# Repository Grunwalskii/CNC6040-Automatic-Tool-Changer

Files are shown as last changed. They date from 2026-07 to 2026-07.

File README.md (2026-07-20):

# CNC6040 Tool Changer

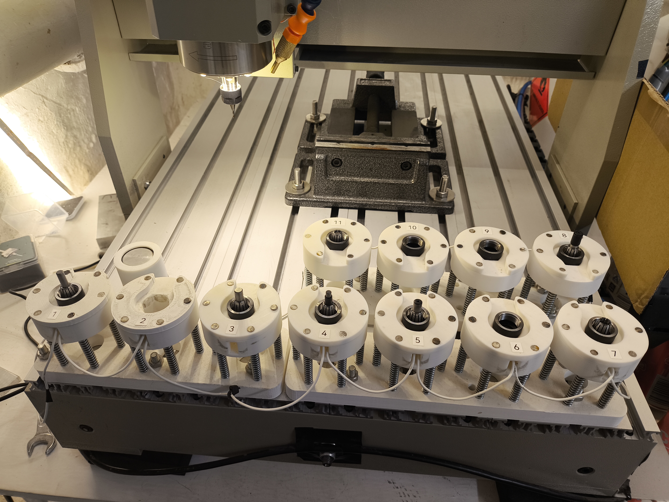
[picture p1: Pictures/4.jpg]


# CNC6040 Tool Changer Configuration & Setup Guide

## Software & Hardware Integration

### 1. Fusion 360 Tool Change Bypass (Personal/Non-Commercial Tier)
The free personal tier of Autodesk Fusion 360 restricts multi-tool operations by stripping out automatic tool change commands (`M6`) and forcing the generation of separate, individual G-code files for each tool. To bypass this limitation and preserve continuous tool paths in a single output file, you must use a batch post-processing add-in.

* **Bypass Tool:** Download and install the [Fusion360-Batch-Post Add-In by TimPaterson](https://github.com/TimPaterson/Fusion360-Batch-Post).
* **Configuration:** 
  1. Open the **Post Process All** menu inside your Fusion 360 Manufacture workspace.
  2. Locate the patch settings area.
  3. Ensure that the **"Use individual operations"** option is enabled/configured as demonstrated in the system images, which re-links operations across multiple tools into a unified G-code sequence.
  4. Ensure your post-processor settings are matched exactly to your specific machine variant's configuration image.

---

### 2. Mach3 Modern Control Interface
To replace the outdated stock Mach3 user interface with a streamlined, modern layout optimized for rapid setup and clear digital readouts (DRO), this build uses a high-performance custom screen set.

* **Control Interface:** [PA Mach 3 Screen Set by Physics Anonymous](https://www.physanon.com/pa-mach-3-screen-set/).
* **Installation:** Extract the downloaded file structure. Place the custom `.set` file directly inside your root `C:\Mach3\` directory, and copy the accompanying UI asset folders into the `Mach3\Bitmaps\` folder. Load the new interface from the Mach3 upper menu bar under **View -> Load Screens**.

---

### 3. CNC6040 USB Control Board Modifications
To safely automate tool change heights and verify secure tool engagement, the standard CNC6040 USB interface board has been modified to accept two dedicated digital inputs:

* **Electric Touch Probe:** Assigned to a specific digital input pin for automatic tool height probing. The spindle/tool must be properly grounded to the CNC chassis. The touchplate is wired directly to the signal line from the controller board, utilizing an internal or external pull-up resistor (configured as Default High) that triggers the circuit when the tool makes physical contact.
* **Tool Presence Sensors:** Implemented inside each tool slot/pocket of the rack using tactile microswitches wired in series to monitor tool insertion status. Because they are chained together, the signal pulls **High** if any single switch is open (indicating a missing or improperly seated tool), and drops **Low** only when all tools are securely in place, instantly halting operations if a tool fails to mount or unmount correctly.
* **Limit Switch Configuration:** To free up and maximize the available input pins on the USB control board for the probe and tool presence sensors, all three physical axis limit switches (X, Y, and Z) have been wired in series to share a single, combined digital input pin.

### 4. Materials & Bill of Materials (BOM)

#### 3D Printed Parts
* **Print Settings:** Print all provided STL files using any standard structural filament (e.g.,PLA, PETG, ABS, or ASA). 
* **Perimeters:** A minimum of **3 wall perimeters**
* **Infill:** A minimum of 20%
  
#### Hardware & Components
To complete the assembly, you will need to source the following off-the-shelf items:

1. **Linear Rods:** 5mm diameter steel rods (Available on [AliExpress](https://de.aliexpress.com/item/4001203233924.html)).
2. **Spring Steel Springs:** 
   * **Wire Diameter:** 0.5 mm
   * **Outer Diameter:** 6.5 mm
   * **Length:** 35 mm
3. Microswitches (Type: HANDLE Available on [AliExpress](https://de.aliexpress.com/item/1005009576690625.html))
4. M6 Screws ~25mm and Nuts
5. Some kind of touchplate (Available on [AliExpress](https://de.aliexpress.com/item/1005008850006833.html)
   
---

## Support

If you enjoy this project and want to support its development, you can buy me a coffee:



---

## ⚠️ Disclaimer & Danger Warning

### 🛑 DANGER: RISK OF MACHINE CRASH & HARDWARE DAMAGE
**Misconfigured tool height sensors, incorrect G-code, or improper macro settings will cause a severe machine crash.** 
Before allowing the spindle to automatically drive a tool down into the touchplate or tool setter, you **must** manually test the circuit logic.

### Disclaimer
This documentation and the provided configurations are shared for educational and personal project use only. Modifying CNC machinery with custom automatic tool changers, custom macro scripts, and un-isolated input circuits carries inherent risks of hardware destruction, electrical damage, and personal injury. The authors assume no liability for damaged components, broken tooling, or ruined workpieces resulting from the use of these guides or files. Proceed at your own risk.

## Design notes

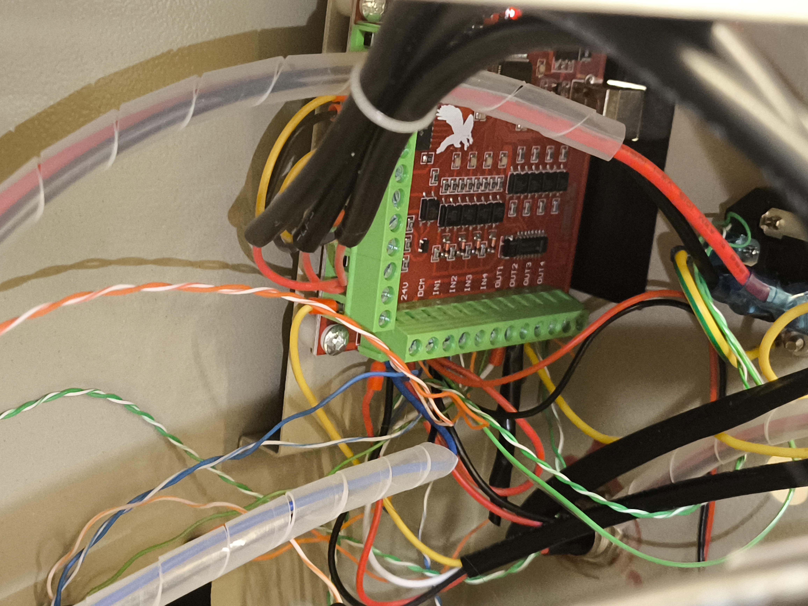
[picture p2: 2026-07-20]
Pictures/CNC6040ControlBoard.jpg

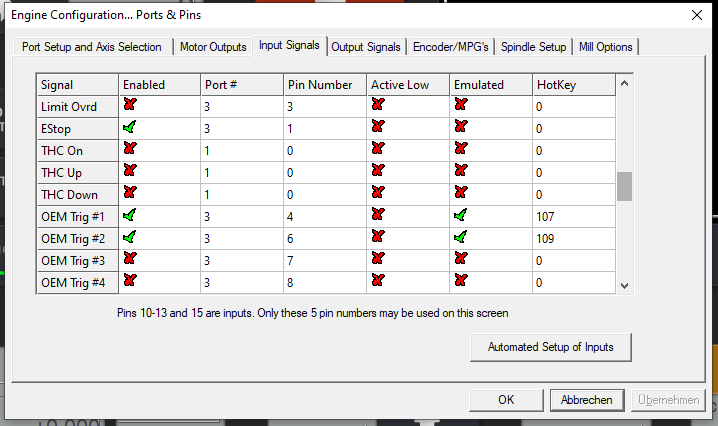
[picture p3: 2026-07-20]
Mach3/Screenshots/{6C5813CC-ED11-40CD-9C9B-76047EAF6F08}.png

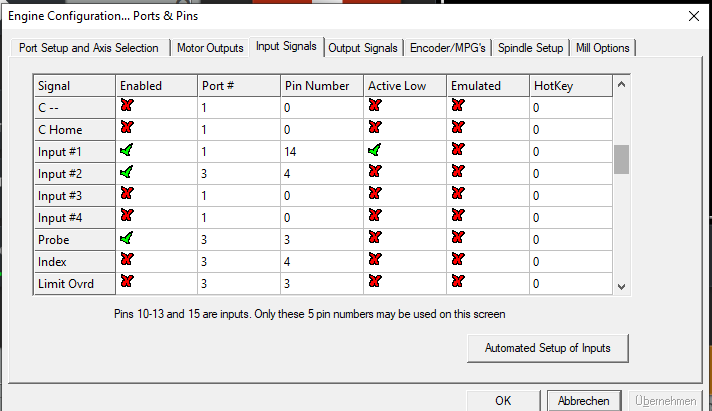
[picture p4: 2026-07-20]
Mach3/Screenshots/{B6C7E7E9-AD3A-4B73-86B3-040BA170EC96}.png

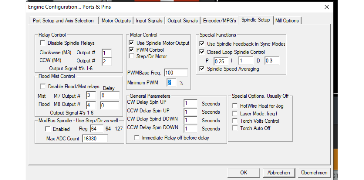
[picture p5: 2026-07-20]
Mach3/Screenshots/{8947AC09-7EBE-4D3E-AFD2-93C5BA618787}.png

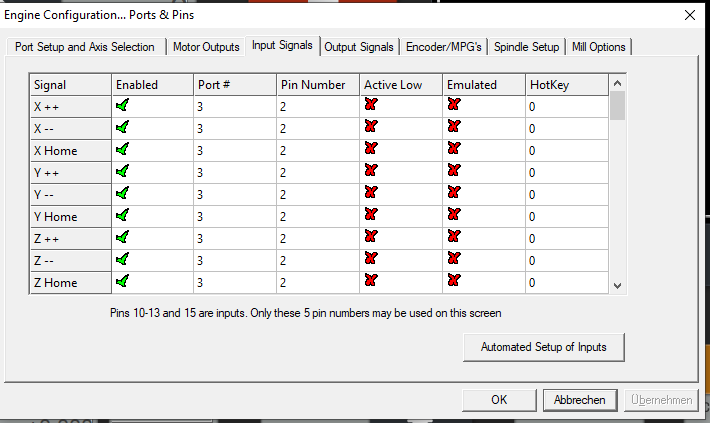
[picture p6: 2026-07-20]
Mach3/Screenshots/{093C688A-DDCC-42CD-9133-025AB5DC0939}.png

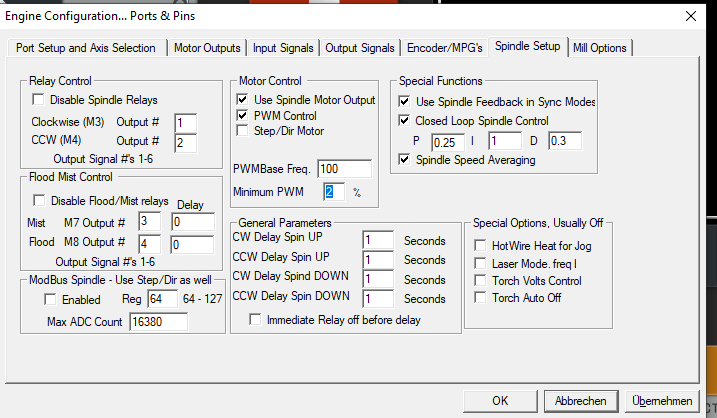
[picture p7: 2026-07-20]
Mach3/Screenshots/{43C4AFD6-ACA7-47BE-B736-4CE7A371A08D}.png

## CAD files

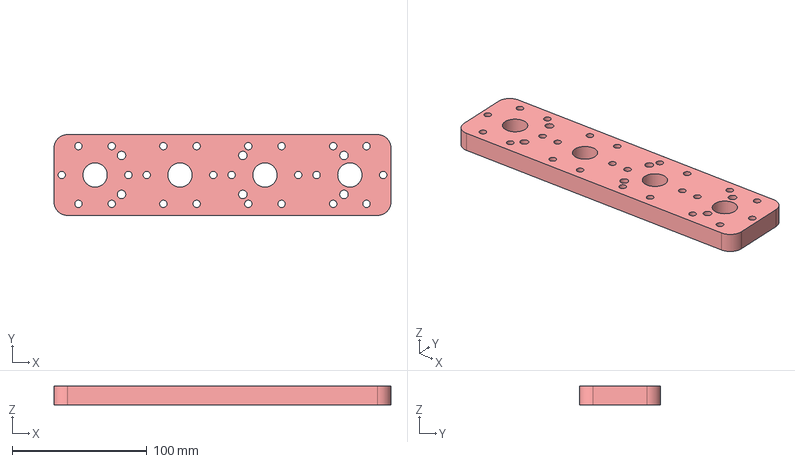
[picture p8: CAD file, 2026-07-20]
GrundplatteX4.step
250.0 x 60.0 x 14.0 mm

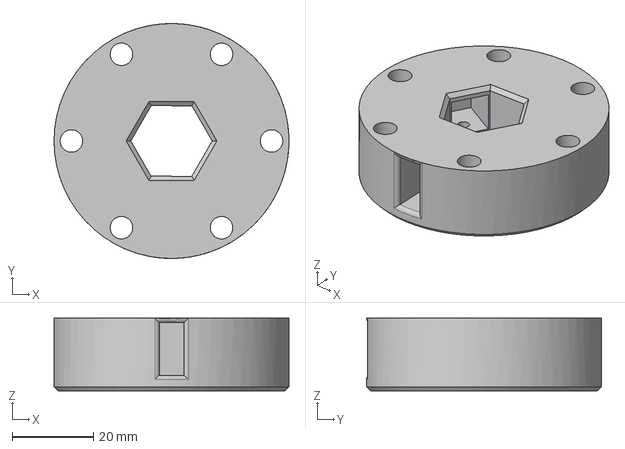
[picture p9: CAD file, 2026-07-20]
Kranz.step
58.0 x 58.0 x 18.0 mm

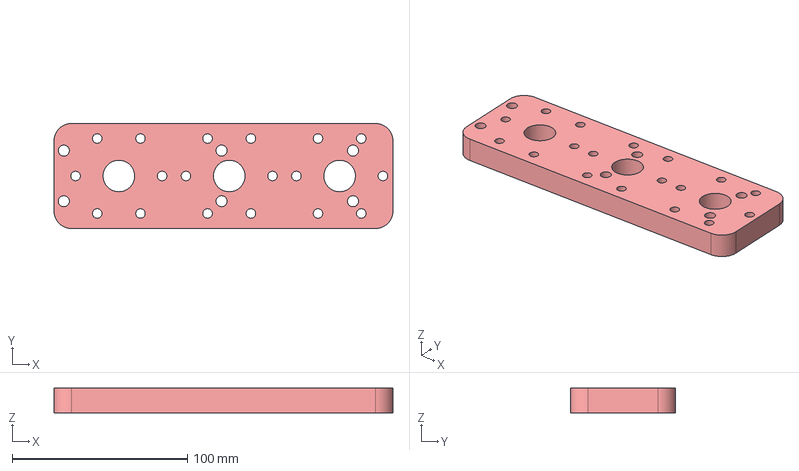
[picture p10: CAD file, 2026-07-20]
GrundplatteX3.step
193.4 x 60.0 x 14.0 mm

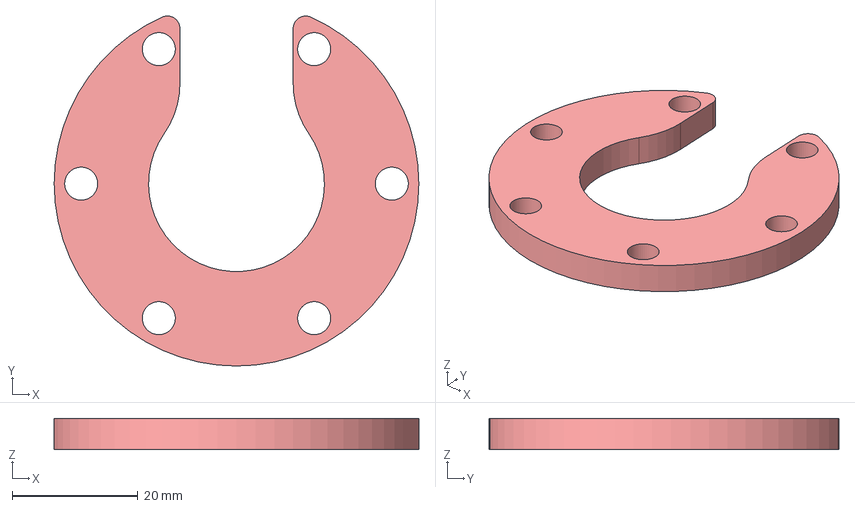
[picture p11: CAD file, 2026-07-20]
Deckel.step
58.0 x 55.7 x 5.00 mm

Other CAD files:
CNC6040ToolChanger.f3d
